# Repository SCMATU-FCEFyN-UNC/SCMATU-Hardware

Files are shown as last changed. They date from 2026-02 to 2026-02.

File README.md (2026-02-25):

# SCMATU-Hardware
Hardware design for the thesis project "SCMATU," developed to excite and measure PZT ultrasonic transducers for automatic resonance frequency determination. The system provides a controlled sinusoidal excitation stage (±10 V), voltage and current sensing circuitry, and signal conditioning to enable accurate phase measurement between voltage and current during frequency sweeps.

---

## Repository Initialization

To obtain this repository locally, use the following commands:

### 1. Initialize Local Repository

```bash
cd your_local_directory
git init
```

### 2. Mark Directory as Safe (If Required)

Some environments may require explicitly marking the repository as safe.

- Bash (Git Bash, WSL, macOS Terminal, Linux):

```bash
git config --global --add safe.directory "$(pwd)"
```

- PowerShell:

```powershell
git config --global --add safe.directory "%cd%"
```

### 3. Add Remote Repository and Pull Branches

```bash
git remote add origin https://github.com/SCMATU-FCEFyN-UNC/SCMATU-Hardware.git
git pull origin main
```

> KiCad v7.0 or later is recommended to open the project files.

---

## 📄 Documentation

- [Schematic](docs/Complete_Schematic.pdf)
- [Hardware Requirements Specification](docs/requirements.md)

---

# License

This project is licensed under the MIT License.

See the [LICENSE](LICENSE) file for full license text.

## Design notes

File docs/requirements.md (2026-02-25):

# Hardware Requirements Specification (HRS)
## SCMATU – Ultrasonic Transducer Amplifier Hardware

**Project:** SCMATU – Sistema de Control y Medición de Amplificador para Transductor Ultrasónico  

---

# 1. Introduction

## 1.1 Purpose

This document defines the hardware requirements of the SCMATU system designed to:

- Excite a PZT ultrasonic transducer (or known RLC resonant circuit),
- Measure electrical parameters,
- Provide the necessary analog front-end for automatic resonance frequency determination.

This specification describes only hardware-level requirements. Firmware and software behavior are defined in their respective specifications.

---

# 2. System Objective

The hardware shall support automatic determination of the resonance frequency of a PZT transducer (or equivalent RLC circuit), defined as:

> The frequency at which the current through the device is maximum and in phase with the applied voltage.

---

# 3. Functional Hardware Requirements

---

## HR-01: Sinusoidal Excitation Capability

The hardware shall be capable of exciting the device under test (DUT) with a sinusoidal signal.

### HR-01.1 Frequency Range
The excitation stage shall support a variable frequency range sufficient to cover the expected resonance frequency of the PZT transducer or RLC test circuit.

### HR-01.2 Amplitude
The excitation output shall support a nominal amplitude of:

```
±10 V
```

This amplitude level is selected to be compatible with operational amplifiers powered at:

```
±12 V to ±15 V
```

### HR-01.3 Signal Quality
The excitation signal shall maintain acceptable sinusoidal integrity within the operating frequency range.

---

## HR-02: Voltage Measurement Capability

The hardware shall provide a measurement path for the voltage applied to the DUT.

### HR-02.1 Measurement Type
The measurement shall capture the peak voltage value.

### HR-02.2 Signal Conditioning
The voltage measurement stage shall:

- Scale the signal to match ADC input range.
- Provide appropriate filtering to reduce noise.
- Ensure safe voltage levels at the microcontroller input.

---

## HR-03: Current Measurement Capability

The hardware shall provide a measurement path for the current flowing through the DUT.

### HR-03.1 Measurement Method
Current shall be measured indirectly using a shunt resistor and signal conditioning stage.

### HR-03.2 Signal Conditioning
The current measurement stage shall:

- Amplify the shunt voltage appropriately.
- Scale the signal to the ADC input range.
- Provide filtering to reduce high-frequency noise.
- Ensure safe operation under expected current levels.

---

## HR-04: Phase Measurement Support

The hardware shall provide signals suitable for phase difference measurement between voltage and current.

### HR-04.1 Signal Availability
Both voltage and current measurement signals shall be accessible in a form suitable for:

- Zero-cross detection, or
- Time-based comparison using digital or analog thresholding.

### HR-04.2 Signal Integrity
The conditioning circuits shall preserve waveform shape sufficiently to allow accurate phase determination.

---

## HR-05: Frequency Sweep Support

The hardware shall support frequency sweeping across the configured operating range without:

- Excessive amplitude distortion,
- Thermal instability,
- Component saturation,
- Instability in the amplification stage.

---

# 4. Electrical Constraints

## EC-01: Supply Voltage

The hardware shall operate with supply rails compatible with:

```
±12 V to ±15 V (analog stage)
+5 V or +3.3 V (digital stage, depending on MCU design)
```

---

## EC-02: Safe Operating Limits

The hardware shall ensure:

- ADC inputs remain within microcontroller safe limits.
- Operational amplifiers remain within linear operating regions.
- The DUT is not exposed to unsafe overvoltage conditions under normal operation.

---

# 5. Measurement Accuracy Considerations

The hardware design shall:

- Minimize noise in voltage and current measurement paths.
- Ensure stable gain characteristics.
- Provide predictable scaling factors for firmware calibration.

Final phase precision and resonance determination accuracy depend on combined hardware and firmware implementation.

---

# 6. System Interfaces

The hardware shall provide:

- Interface to microcontroller ADC inputs.
- Interface to frequency generation module (e.g., DDS).
- Interface to power amplification stage.
- Electrical connection to DUT (PZT transducer or RLC test circuit).

---

# 7. Definitions

**DUT (Device Under Test):**  
PZT ultrasonic transducer or known RLC resonant circuit.

**Resonance Frequency:**  
Frequency at which current is maximum and phase difference between voltage and current approaches zero.

---

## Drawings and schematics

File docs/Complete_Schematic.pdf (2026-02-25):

R302

R102

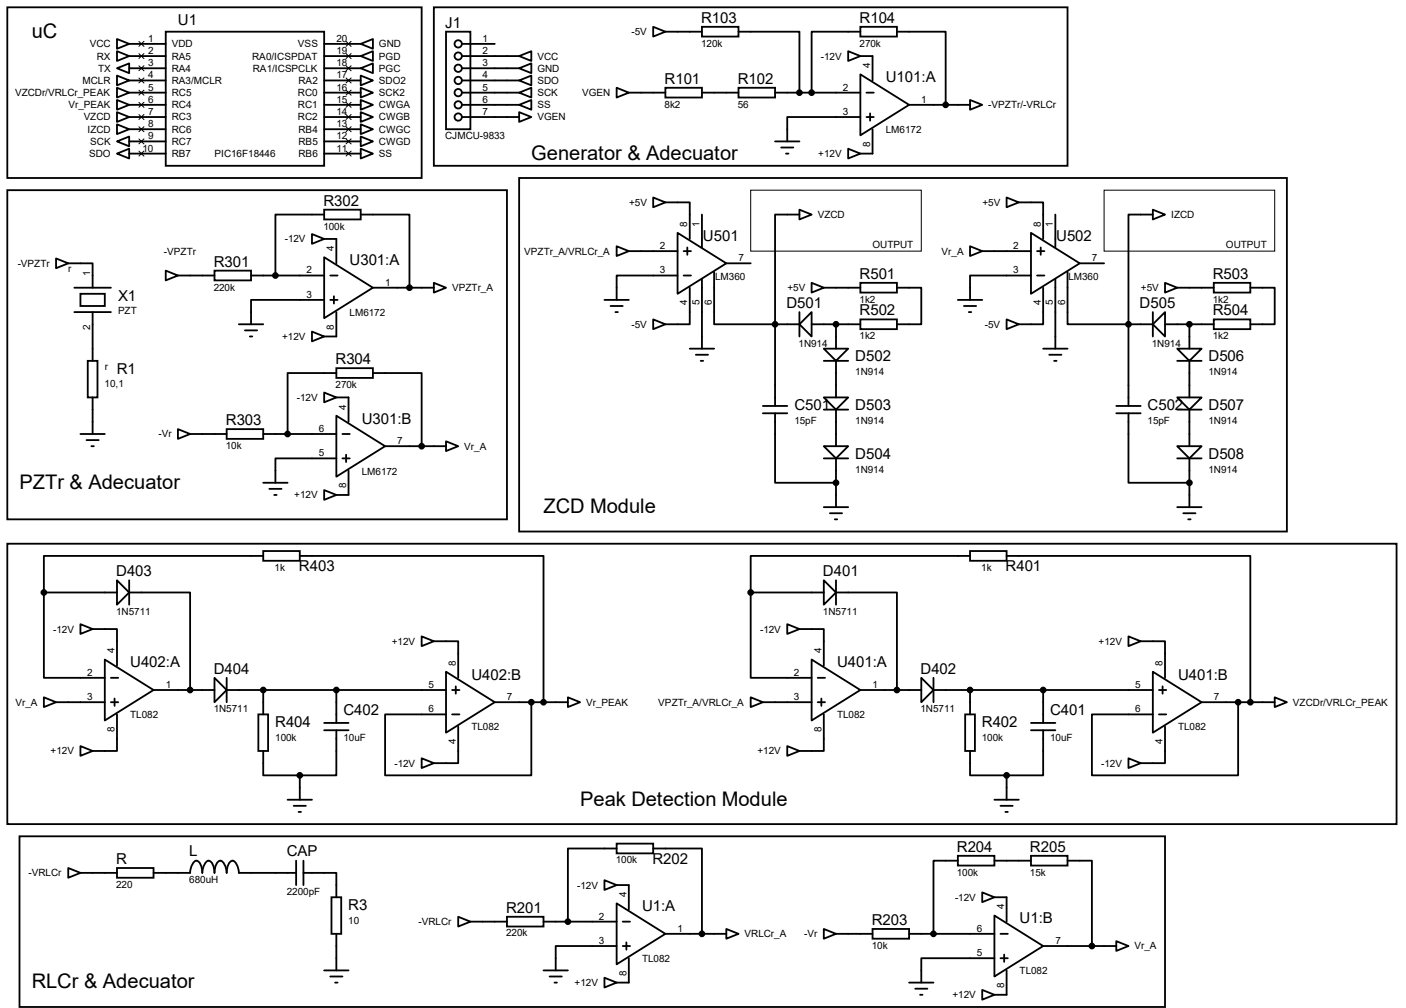
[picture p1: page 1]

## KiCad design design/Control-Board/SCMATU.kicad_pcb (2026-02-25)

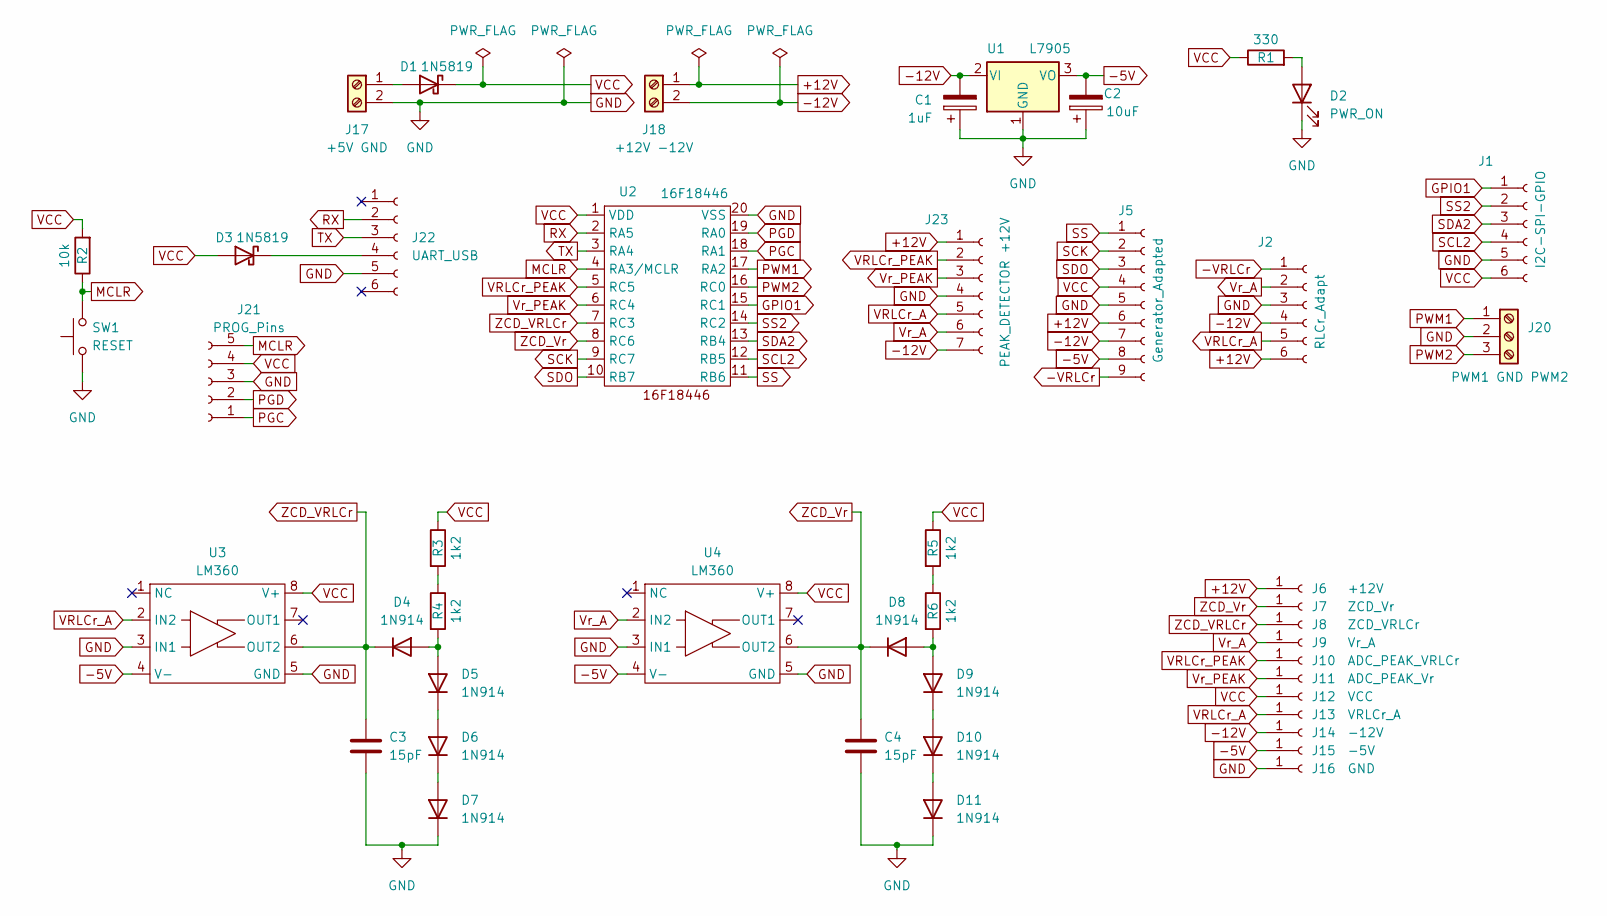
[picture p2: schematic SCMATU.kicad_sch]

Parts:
C1: 1uF; CP_Radial_D5.0mm_P2.00mm
C2: 10uF; CP_Radial_D5.0mm_P2.00mm
C3, C4: 15pF; C_Disc_D5.0mm_W2.5mm_P2.50mm
D1, D3: 1N5819; D_DO-41_SOD81_P10.16mm_Horizontal
D2: PWR_ON; LED_D5.0mm_IRGrey
D4, D5, D6, D7, D8, D9, D10, D11: 1N914; D_DO-35_SOD27_P7.62mm_Horizontal
J1: I2C-SPI-GPIO; PinHeader_1x06_P2.54mm_Vertical
J2: RLCr_Adapt; PinHeader_1x06_P2.54mm_Vertical
J5: Generator_Adapted; PinHeader_1x09_P2.54mm_Vertical
J6: +12V; PinHeader_1x01_P2.54mm_Vertical
J7: ZCD_Vr; PinHeader_1x01_P2.54mm_Vertical
J8: ZCD_VRLCr; PinHeader_1x01_P2.54mm_Vertical
J9: Vr_A; PinHeader_1x01_P2.54mm_Vertical
J10: ADC_PEAK_VRLCr; PinHeader_1x01_P2.54mm_Vertical
J11: ADC_PEAK_Vr; PinHeader_1x01_P2.54mm_Vertical
J12: VCC; PinHeader_1x01_P2.54mm_Vertical
J13: VRLCr_A; PinHeader_1x01_P2.54mm_Vertical
J14: -12V; PinHeader_1x01_P2.54mm_Vertical
J15: -5V; PinHeader_1x01_P2.54mm_Vertical
J16: GND; TestPoint_Pad_10.0x10.0mm
J17: +5V GND; TerminalBlock_Plug_Bornier-2-P5.08mm
J18: +12V -12V; TerminalBlock_Plug_Bornier-2-P5.08mm
J20: PWM1 GND PWM2; PinHeader_1x03_P2.54mm_Vertical
J21: PROG_Pins; PinHeader_1x05_P2.54mm_Vertical
J22: UART_USB; PinHeader_1x06_P2.54mm_Horizontal
J23: PEAK_DETECTOR +12V; PinHeader_1x07_P2.54mm_Vertical
R1: 330; R_Axial_DIN0207_L6.3mm_D2.5mm_P10.16mm_Horizontal
R2: 10k; R_Axial_DIN0207_L6.3mm_D2.5mm_P10.16mm_Horizontal
R3, R4, R5, R6: 1k2; R_Axial_DIN0207_L6.3mm_D2.5mm_P10.16mm_Horizontal
SW1: RESET; SW_PUSH_6mm
U1: L7905; TO-220-3_Vertical
U2: 16F18446; SOIC-20W_7.5x12.8mm_P1.27mm
U3, U4: LM360; DIP-8_W7.62mm_Socket_LongPads

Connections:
+12V: J2.6, J5.6, J6.1, J18.1, J23.1
-5V: C2.2, J5.8, J15.1, U1.3 (VO), U3.4 (V-), U4.4 (V-)
-12V: C1.2, J2.4, J5.7, J14.1, J18.2, J23.7, U1.2 (VI)
-VRLCr: J2.1, J5.9
GND: C1.1, C2.1, C3.2, C4.2, D2.1 (K), D7.1 (K), D11.1 (K), J1.5, J2.3, J5.5, J16.1, J17.2, J20.2, J21.3, J22.5, J23.4, SW1.1, U1.1 (GND), U2.20 (VSS), U3.3 (IN1), U3.5 (GND), U4.3 (IN1), U4.5 (GND)
GPIO1: J1.1, U2.15 (RC1)
MCLR: J21.5, R2.1, SW1.2, U2.4 (RA3/MCLR)
unnamed: D1.2 (A), J17.1
unnamed: D2.2 (A), R1.2
unnamed: D3.1 (K), J22.4
unnamed: D4.2 (A), D5.2 (A), R4.2
unnamed: D5.1 (K), D6.2 (A)
unnamed: D6.1 (K), D7.2 (A)
unnamed: D8.2 (A), D9.2 (A), R6.2
unnamed: D9.1 (K), D10.2 (A)
unnamed: D10.1 (K), D11.2 (A)
unnamed: R3.2, R4.1
unnamed: R5.2, R6.1
PGC: J21.1, U2.18 (RA1)
PGD: J21.2, U2.19 (RA0)
PWM1: J20.1, U2.17 (RA2)
PWM2: J20.3, U2.16 (RC0)
RX: J22.2, U2.2 (RA5)
SCK: J5.2, U2.9 (RC7)
SCL2: J1.4, U2.12 (RB5)
SDA2: J1.3, U2.13 (RB4)
SDO: J5.3, U2.10 (RB7)
SS: J5.1, U2.11 (RB6)
SS2: J1.2, U2.14 (RC2)
TX: J22.3, U2.3 (RA4)
VCC: D1.1 (K), D3.2 (A), J1.6, J5.4, J12.1, J21.4, R1.1, R2.2, R3.1, R5.1, U2.1 (VDD), U3.8 (V+), U4.8 (V+)
VRLCr_A: J2.5, J13.1, J23.5, U3.2 (IN2)
VRLCr_PEAK: J10.1, J23.2, U2.5 (RC5)
Vr_A: J2.2, J9.1, J23.6, U4.2 (IN2)
Vr_PEAK: J11.1, J23.3, U2.6 (RC4)
ZCD_VRLCr: C3.1, D4.1 (K), J8.1, U2.7 (RC3), U3.6 (OUT2)
ZCD_Vr: C4.1, D8.1 (K), J7.1, U2.8 (RC6), U4.6 (OUT2)

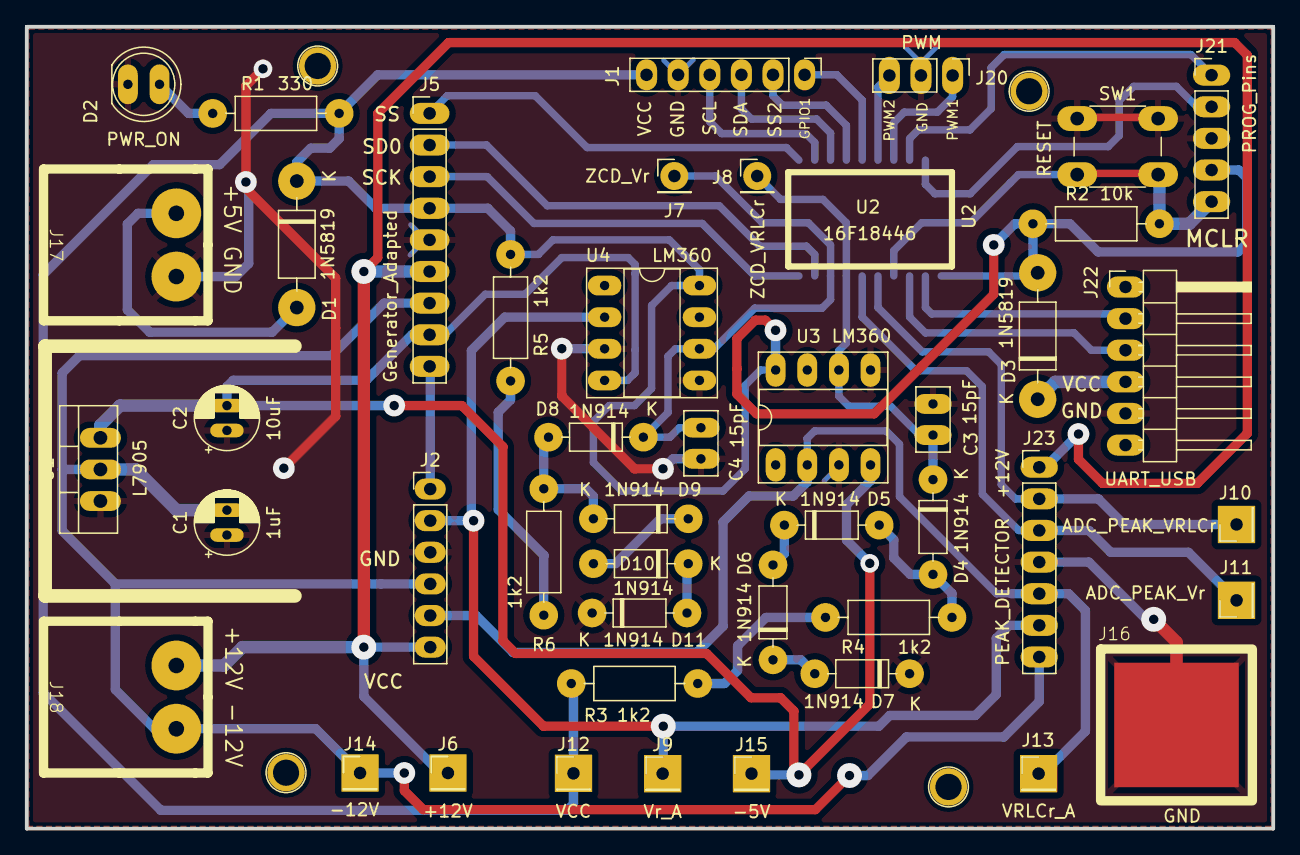
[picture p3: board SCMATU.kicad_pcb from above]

Board: 2 copper layers, 100.1 x 64.4 mm, 46 parts (1 on the bottom side), 37 nets.

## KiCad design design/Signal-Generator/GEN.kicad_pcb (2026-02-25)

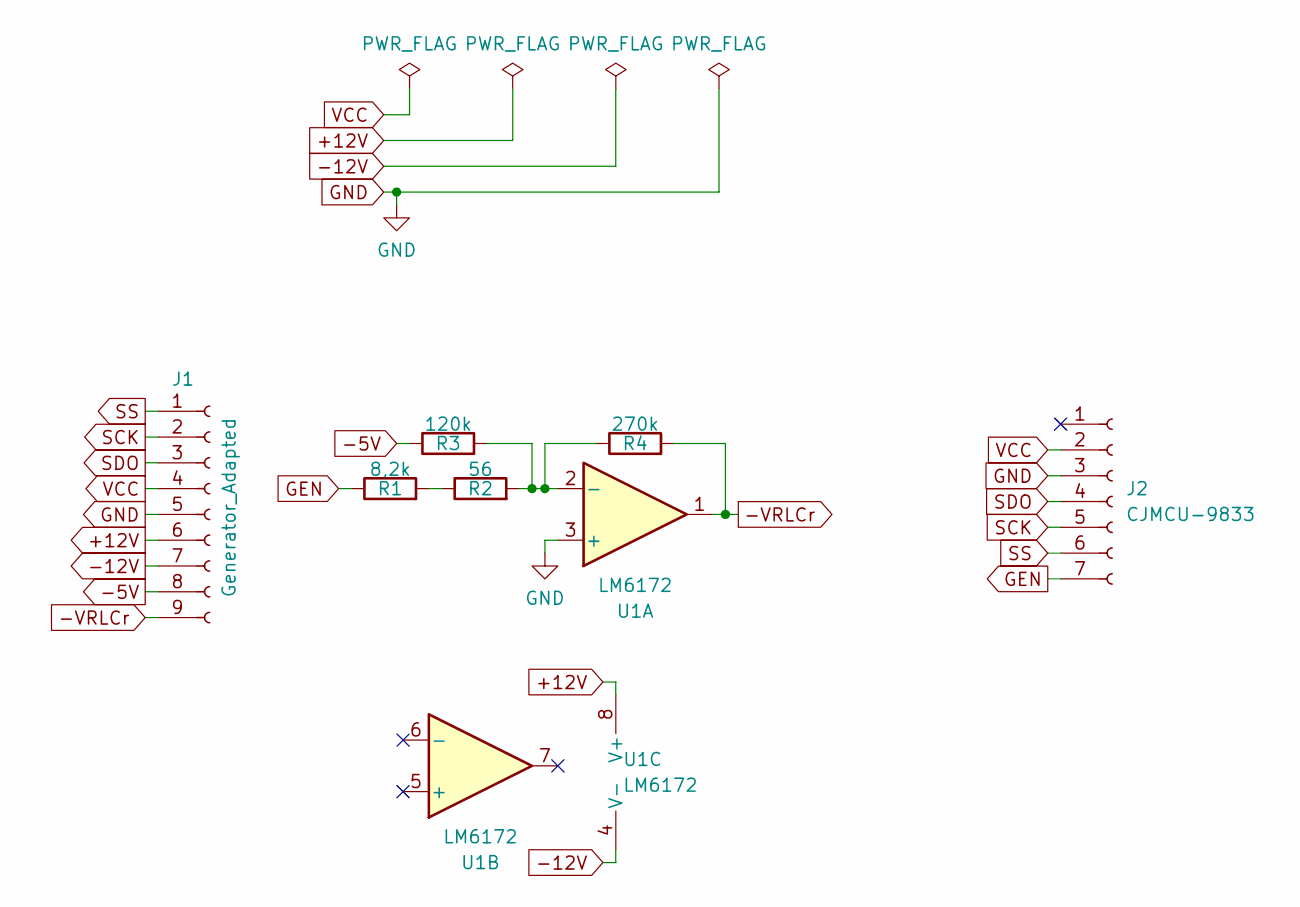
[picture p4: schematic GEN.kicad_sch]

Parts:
J1: Generator_Adapted; PinHeader_1x09_P2.54mm_Vertical
J2: CJMCU-9833; PinHeader_1x07_P2.54mm_Horizontal
R1: 8,2k; R_Axial_DIN0207_L6.3mm_D2.5mm_P10.16mm_Horizontal
R2: 56; R_Axial_DIN0207_L6.3mm_D2.5mm_P10.16mm_Horizontal
R3: 120k; R_Axial_DIN0207_L6.3mm_D2.5mm_P10.16mm_Horizontal
R4: 270k; R_Axial_DIN0207_L6.3mm_D2.5mm_P10.16mm_Horizontal
U1: LM6172; DIP-8_W7.62mm_Socket_LongPads

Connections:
+12V: J1.6, U1.8 (V+)
-5V: J1.8, R3.1
-12V: J1.7, U1.4 (V-)
-VRLCr: J1.9, R4.2, U1.1
GEN: J2.7, R1.1
GND: J1.5, J2.3, U1.3 (+)
unnamed: R1.2, R2.1
unnamed: R2.2, R3.2, R4.1, U1.2 (-)
SCK: J1.2, J2.5
SDO: J1.3, J2.4
SS: J1.1, J2.6
VCC: J1.4, J2.2

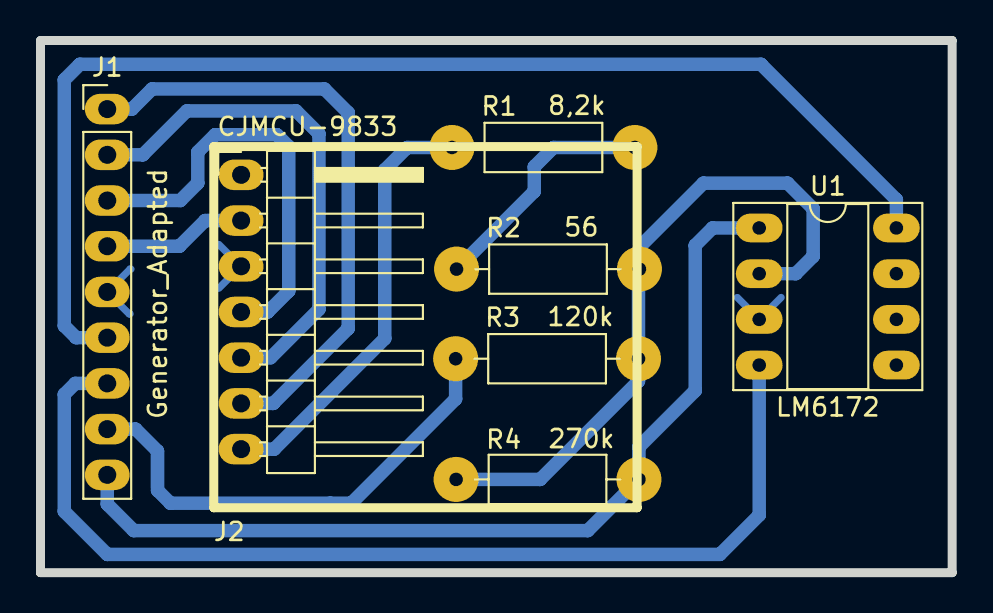
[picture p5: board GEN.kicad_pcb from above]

Board: 2 copper layers, 50.6 x 29.6 mm, 7 parts (0 on the bottom side), 12 nets.

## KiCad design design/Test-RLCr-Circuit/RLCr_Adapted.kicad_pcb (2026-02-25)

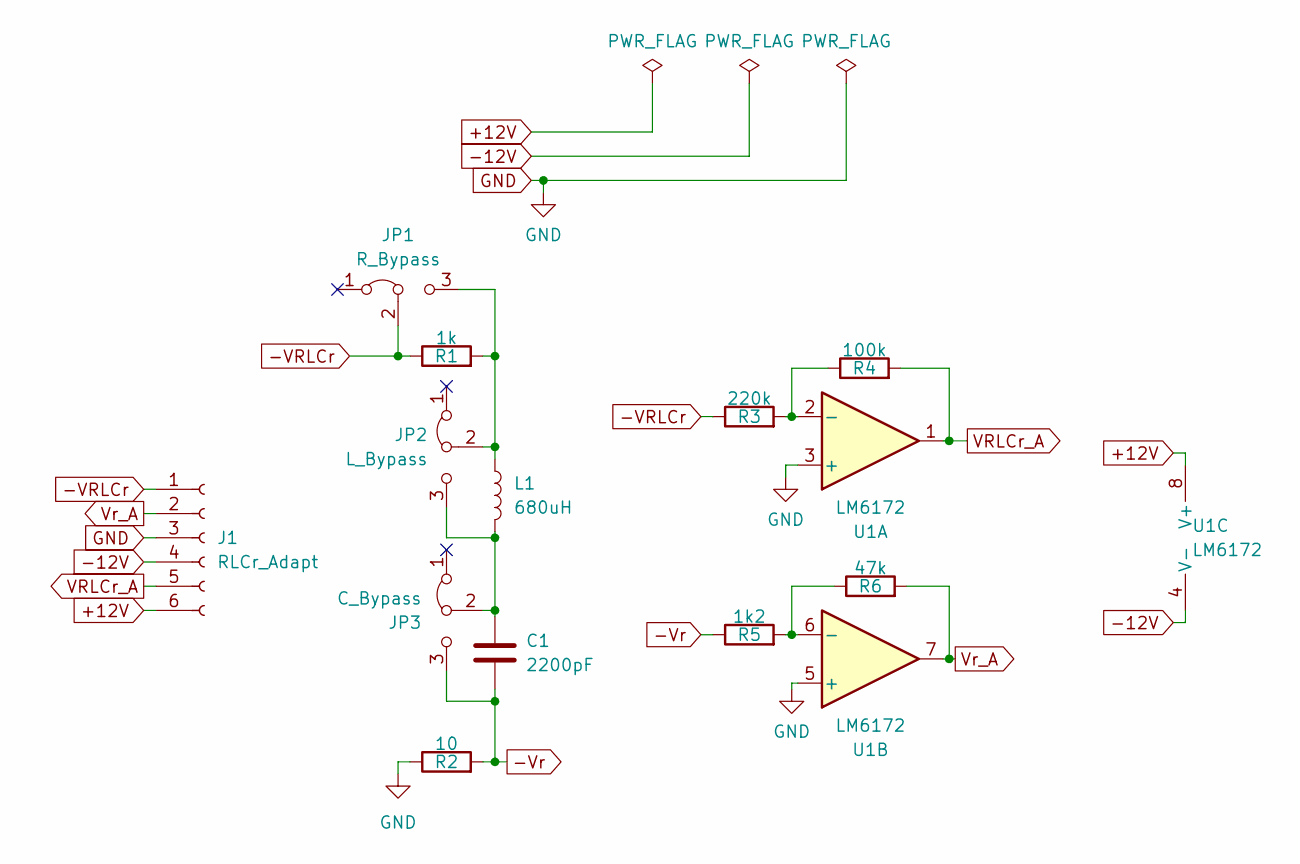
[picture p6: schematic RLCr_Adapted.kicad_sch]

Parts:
C1: 2200pF; C_Disc_D5.0mm_W2.5mm_P2.50mm
J1: RLCr_Adapt; PinHeader_1x06_P2.54mm_Vertical
JP1: R_Bypass; PinHeader_1x03_P2.54mm_Vertical
JP2: L_Bypass; PinHeader_1x03_P2.54mm_Vertical
JP3: C_Bypass; PinHeader_1x03_P2.54mm_Vertical
L1: 680uH; L_Axial_L7.0mm_D3.3mm_P10.16mm_Horizontal_Fastron_MICC
R1: 1k; R_Axial_DIN0207_L6.3mm_D2.5mm_P10.16mm_Horizontal
R2: 10; R_Axial_DIN0207_L6.3mm_D2.5mm_P10.16mm_Horizontal
R3: 220k; R_Axial_DIN0207_L6.3mm_D2.5mm_P10.16mm_Horizontal
R4: 100k; R_Axial_DIN0207_L6.3mm_D2.5mm_P10.16mm_Horizontal
R5: 1k2; R_Axial_DIN0207_L6.3mm_D2.5mm_P10.16mm_Horizontal
R6: 47k; R_Axial_DIN0207_L6.3mm_D2.5mm_P10.16mm_Horizontal
U1: LM6172; DIP-8_W7.62mm_Socket_LongPads

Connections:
+12V: J1.6, U1.8 (V+)
-12V: J1.4, U1.4 (V-)
-VRLCr: J1.1, JP1.2 (C), R1.1, R3.1
-Vr: C1.2, JP3.3 (B), R2.2, R5.1
GND: J1.3, R2.1, U1.3 (+), U1.5 (+)
unnamed: JP1.3 (B), JP2.2 (C), L1.1, R1.2
unnamed: C1.1, JP2.3 (B), JP3.2 (C), L1.2
unnamed: R3.2, R4.1, U1.2 (-)
unnamed: R5.2, R6.1, U1.6 (-)
VRLCr_A: J1.5, R4.2, U1.1
Vr_A: J1.2, R6.2, U1.7

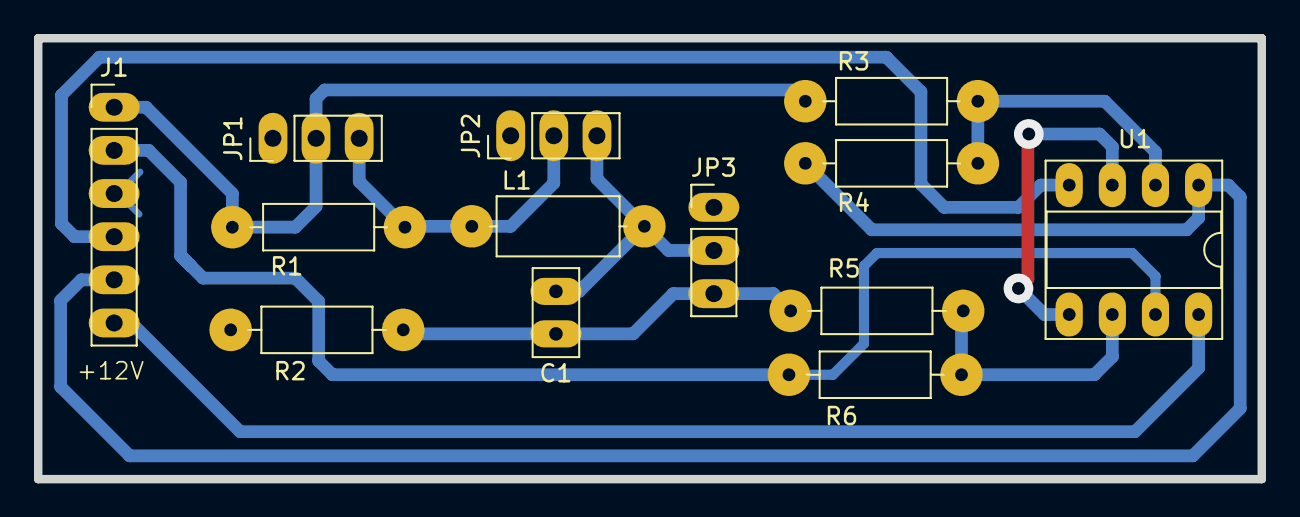
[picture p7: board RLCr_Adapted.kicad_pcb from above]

Board: 2 copper layers, 72.0 x 26.0 mm, 13 parts (0 on the bottom side), 11 nets.

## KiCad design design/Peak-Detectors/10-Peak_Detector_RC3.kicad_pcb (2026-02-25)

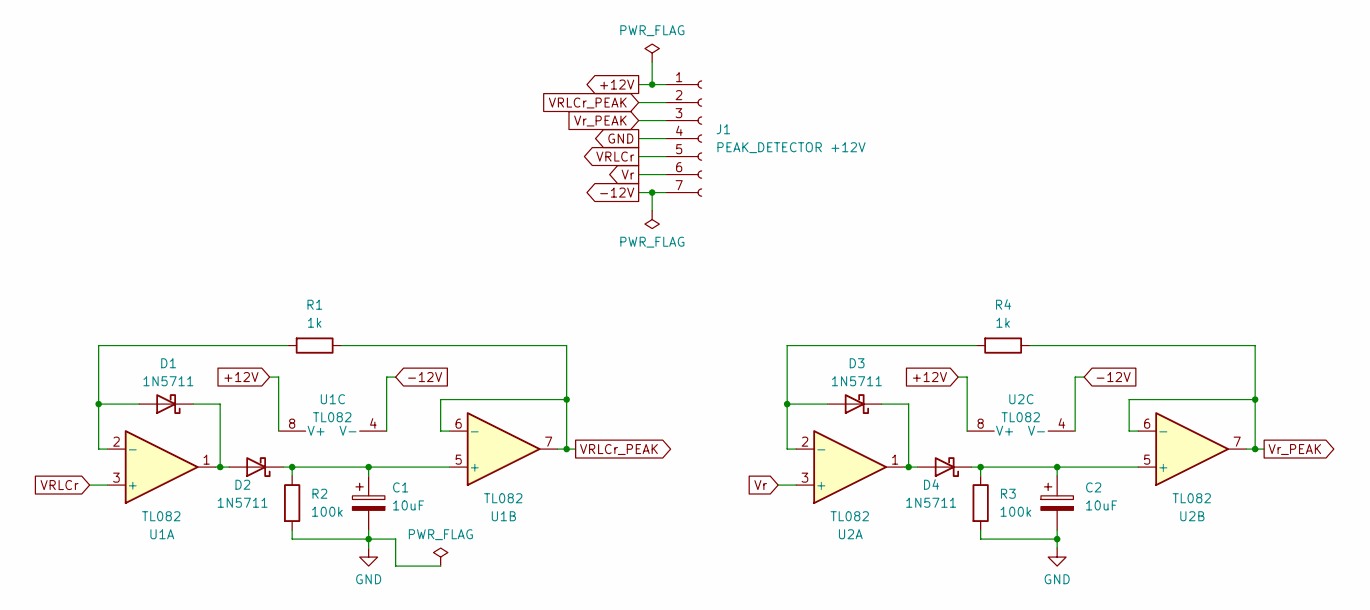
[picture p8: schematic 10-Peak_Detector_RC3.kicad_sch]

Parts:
C1, C2: 10uF; CP_Radial_D5.0mm_P2.00mm
D1, D2, D3, D4: 1N5711; D_DO-35_SOD27_P7.62mm_Horizontal
J1: PEAK_DETECTOR +12V; PinHeader_1x07_P2.54mm_Vertical
R1, R4: 1k; R_Axial_DIN0207_L6.3mm_D2.5mm_P7.62mm_Horizontal
R2, R3: 100k; R_Axial_DIN0207_L6.3mm_D2.5mm_P7.62mm_Horizontal
U1, U2: TL082; DIP-8_W7.62mm_Socket_LongPads

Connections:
+12V: J1.1, U1.8 (V+), U2.8 (V+)
-12V: J1.7, U1.4 (V-), U2.4 (V-)
GND: C1.2, C2.2, J1.4, R2.2, R3.2
unnamed: D1.2 (A), R1.2, U1.2 (-)
unnamed: D1.1 (K), D2.2 (A), U1.1
unnamed: C1.1, D2.1 (K), R2.1, U1.5 (+)
unnamed: D3.2 (A), R4.2, U2.2 (-)
unnamed: D3.1 (K), D4.2 (A), U2.1
unnamed: C2.1, D4.1 (K), R3.1, U2.5 (+)
VRLCr: J1.5, U1.3 (+)
VRLCr_PEAK: J1.2, R1.1, U1.6 (-), U1.7
Vr: J1.6, U2.3 (+)
Vr_PEAK: J1.3, R4.1, U2.6 (-), U2.7

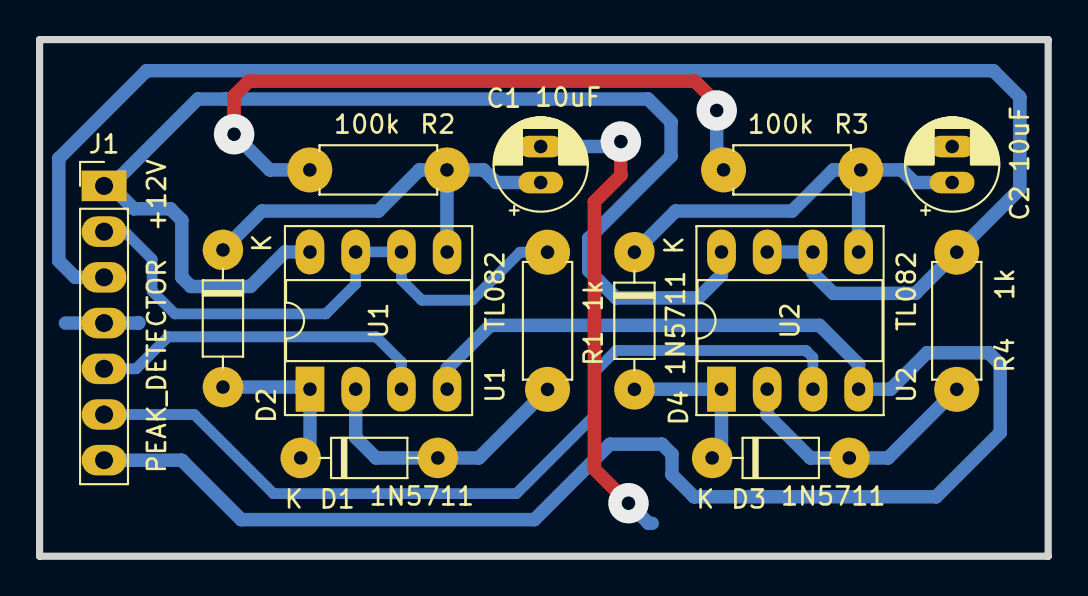
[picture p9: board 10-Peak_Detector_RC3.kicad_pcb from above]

Board: 2 copper layers, 56.0 x 28.7 mm, 13 parts (0 on the bottom side), 13 nets.
